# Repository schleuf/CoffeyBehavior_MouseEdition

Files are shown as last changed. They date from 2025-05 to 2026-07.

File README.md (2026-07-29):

<!-- PROJECT LOGO -->
<br />
<div align="center">
  <h3 align="center">A robust and convenient framework for studying the neurobiological substrates underlying individual, strain, and sex differences in fentanyl use disorder in mice</h3>
</div>

<!-- ABOUT THE PROJECT -->
<!-- TOC -->
- [About The Project](#about-the-project)
- [Prerequisites](#prerequisites)
- [Installation](#installation)
- [Generate Raw Manuscript Figures](#generate-raw-manuscript-figures)
- [Custom Implementations](#custom-implementations)
    - [Hardware Setup](#hardware-setup)
    - [MED Software Setup](#med-software-setup)
    - [MATLAB Software Setup](#matlab-software-setup)
- [Detailed Behaivor Protocol](#detailed-behaivor-protocol)
    - [Before Running Behavior](#before-running-behavior)
    - [Running Behavior](#running-behavior)
    - [Planning Cohorts & Ordering Animals](#planning-cohorts--ordering-animals)
    - [Week 0](#week-0)
    - [Week 1](#week-1)
    - [Weeks 2 & 3 Self-Administration](#weeks-2--3-self-administration)
    - [Week 4 & 5 Extinction](#week-4--5-extinction)
    - [Week 6 Reinstatement](#week-6-reinstatement)
    - [Alternative Week 4 Behavioral Economics](#alternative-week-4-behavioral-economics)
<!-- /TOC -->

# About The Project
This GitHub repository contains the code neccessary to generate the figures presented in PUBLICATION INFORMATION

This repository also contains a comprehensive guide for setting up oral fentanyl self-administration and using the accompanying software to analyse the data in a flexible and user friendly manor.

<!-- Prerequisites -->
# Prerequisites
Implementation of the full behavioral pipeline requires Med-PC 4.0 or later (Med-Associates)    

The analysis code has been tested on MATLAB 2024a and later

Required MATLAB Toolboxes:
   ```sh
Curve Fitting Toolbox™   
Statistics and Machine Learning Toolbox™
   ```

Required External Packages:
>https://github.com/piermorel/gramm

# Installation

This Github Repository can be cloned manually, through GitHub Desktop, or through git commands

   ```sh
   git clone https://github.com/schleuf/CoffeyBehavior_MouseEdition
   ```

<!-- USAGE EXAMPLES -->
# Generate Raw Manuscript Figures
Open MATLAB and Navigate to the parent directory for this repository

Run:

   ```sh
   main_MouseSABehavior
   ```

# Custom Implementations
## Hardware Setup
### Single Chamber Parts List  
| Description | Manufacturer | Part # |
|---|---|---|
| Outer Cabinet (1 chamber) | SUNCAST | BMCCPD3000 |
| Outer Cabinet (3 chamber) | SUNCAST | BMCCPD8004 |
| Acoustic Isolation Foam | Auralex | PYRAMIDCHA |
| Camera | Arducam | B0506 |
| Microphone | Pettersson Elektronik | M500-384 |
| Modular Test Chamber Mouse | Med-Associates | ENV-307A |
| Stainless Steel Floor | Med-Associates | ENV-307A-GFW |
| House Light (classic) | Med-Associates | ENV-315M-LED |
| House Light (red) | Med-Associates | ENV-315M-LED |
| Retractable Lever (classic) x2 | Med-Associates | ENV-312-3M |
| Stimulus Light (classic) x2 | Med-Associates | ENV-321M-LED |
| Liquid Delivery Receptacle (tall) | Med-Associates | ENV-303LPHD-4.25 |
| Syringe Pump (3.33RPM) | Med-Associates | PHM-200 |
| Head Entry Detector | Med-Associates | ENV-254-FB |
| SmartCtrl Card | Med-Associates | DIG-716P1 |
| SmartCtrl Panel | Med-Associates | SG-716B |
| Tone Generator | Med-Associates | ENV-323AM |
| Angled Top | 3D Printed | \3D Printed Parts |

### Chamber Wiring
 |     Med-PC #     |     Description    |     Note    |
|---|---|---|
|     Output 1    |     Left Lever Out    |     Active Lever    |
|     Output 2    |     Right Lever Out     |     Optional (Not used in our setup)    |
|     Output 3    |     House Light On    |     Optional   (Not used in our setup)    |
|     Output 4    |     Red House Light On    |     Optional   (Not used in our setup)    |
|     Output 5    |     Left Lever Light    |     Active Lever Stimulus Light    |
|     Output 6    |     Tone On    |     Active   Lever Press Stimulus Tone    |
|     Output 7    |     Right Lever Light    |     Optional   (Not used in our setup)    |
|     Output 8    |     Pump On    |     Liquid Delivery Pump    |
|     Input 1    |     Left Lever In    |     Active Laver    |
|     Input 2    |     Right Lever In    |     Optional (Not used in our setup)    |
|     Input 3    |     Inactive Lever In    |     Non-Retractable Inactive Lever    |
|     Input 4    |     Beam Break In    |     Head Entry Detector for Liquid   Port    |

### Top Down Chamber View


## MED Software Setup
Med-PC Code is available in the folder below and must be compiled prior to use. Inputs and Outputs are defined near the top of the code and may be customezed. Variables for session length, cue timing, pump duration, etc. may be modified in the code or through the Macro.
>./MedPC/MPC/Golden_Liq_SelfAdmin.MPC

   ```sh
   # Editable Inputs, Outputs, and Variable Examples

#  Outputs
    ^LeftLevOut     = 1 
    ^RightLevOut    = 2 
    ^HouseLt        = 3
    ^HouseLtRed     = 4 
    ^LeftLevLt      = 5
    ^RightLevLt     = 7 
    ^Tone           = 6
    ^LiquidDel      = 8
    ^Fan            = 16

#  Inputs
    ^LeftLevIn        = 1 
    ^RightLevIn       = 2 
    ^InactiveIn       = 3
    ^HeadEntry        = 4

# Default setup and trial timing
S.S.1,     
   S1,
     0": ON^Fan;
         SET A(2)  = 180;    \Session length (min)
         SET A(3)  = 4;      \Liquid delivery duration (sec)
         SET A(4)  = 0;      \Lev light delay (sec)
         SET A(5)  = 5;      \Lev light duration (sec)
         SET A(6)  = 0;      \Tone delay (sec)
         SET A(7)  = 5;      \Tone duration (sec)
         SET A(8)  = 0;      \Mag light delay (sec)
         SET A(9)  = 0;      \Mag light duration (sec)
         SET A(10) = 1;      \Active Lev (0:Right 1:Left)
         SET A(11) = 0;      \Liquid delivery delay (sec)
         SET A(12) = 10;     \Total timeout time - time liquid unavailable (sec)
         SET A(16) = 320;    \Maximum Infusions before syringe is empty
         SET A(13) = 180;    \Auto drug delivered (sec) MUST BE SET WITH MACRO IF THIS IS COMMENTED OUT
   ```

Example Med-PC Macros are also available to define subject details, start experiments, and administer shaping rewards through K-Pulses 
>./MedPC/Macro/Golden_Liq_SelfAdmin.MAC

   ```sh
   # Example Macro Text

   TEXTINPUTBOX "Subject in Box 1" "Enter Subject ID:" "S1" #SubB1 
NUMERICINPUTBOX "Weight for Box 1" "Enter weight (grams):" "25" #WeightB1 
NUMERICINPUTBOX "Self-Administration Session" "Enter Training Day:" "1" #SessionB1 
NUMERICINPUTBOX "Auto Shaping Timer" "Enter time between automatic rewards (s)" "60" #ShapeTimeB1
LOAD BOX 1 SUBJ #SubB1 EXPT OralFentSA GROUP One PROGRAM Golden_Liq_SelfAdmin
SET A(13) VALUE #ShapeTimeB1 MAINBOX 1 BOXES 1
SET A(14) VALUE #WeightB1 MAINBOX 1 BOXES 1
SET A(15) VALUE #SessionB1 MAINBOX 1 BOXES 1
   ```
   
## MATLAB Software Setup
The provided MATLAB code can be flexibly modified to run new data generated by your version of Liq_SelfAdmin.MPC
> ./main_MouseSABehavior.m

### Minimal Requirements
- Behavior data  in ./All Behavior
- Experiment Key File: "Experiment Key.xlsx" with following variables (See example)
  - "Run" (number)
  - "Experiment" (categorical: ER, BE, SA)
  - "Date" (Datetime)  - Session (number)
  - "Session Type" (categorical: PreTraining, Training, Extinction, Reinstatement, BehavioralEconomics)
  - "Fentanyl Concentration (ug/ml)" (number)
  - "Volume per dose (mL)" (number)

- Subject Key File: "Subject Key.xlsx" with the following variables (See example, adding extra variables is ok)
  - "Tag Number" (Categorical)
  - "Run" (Number)
  - "Strain" (Categorical)
  - "SelfAdministration" (Logical)
  - "Extinction" (Logical)
  - "Reinstatement" (Logical)
  - "BehavioralEconimics" (Logical)
  - "InlcludeBehavior" (Logical)
  - "RemoveSession" {Cell of Numbers}

### All User Editable Variables are available and described in the first block of code.
   ```sh
# USER EDITABLE SETTINGS
runNum = 'all'; # options: 'all' or desired runs separated by underscores. Must match numbers in Experiment Key (e.g. '1', '1_3_4', '3_2')
runType = 'all'; # options: 'ER' (SA & Extinction & Reinstatement), 'BE' (Behavioral Economics), 'SA' (Self Administration), 'all' (All run seperately)
createNewMasterTable = true; # true: generates & saves a new master table from medPC files in datapath. false: reads mT in from masterTable_flnm if set to false, otherwise 
firstHour = true; # true: acquire data from the first-hour of data and analyze in addition to the full sessions (Important for camparing behavior to 1h reinstatement session).
excludeData = true; # true: excludes data based on the 'RemoveSession' column of Subject Key
acquisition_thresh = 10; # to be labeled as "Acquire", animal must achieve an average number of infusions in Training sessions greater than this threshold
acquisition_testPeriod = {'Training', 'last', 10}; # determines sessions to average infusions across before applying acquisition_thresh. second value can be 'all', 'first', or 'last'. if 'first' or 'last', there should be a 3rd value giving the number of days to average across, or it will default to 1. 
maxLatency = 360; # maximum time in seconds between an active lever press and head entry to be factored into latency calculations
pAcq = true; # true: plot aquisition histogram to choose threshold 
interpWeights = false; # true: interpolate daily weights from weekly weights
interpWeight_sessions = [1,6,11,16,21]; # [sessions with true weights for interpolation]
addROI = true; #true: append master table with ROI data - Requires ROI data sheets with "TagNumber" column and "Video" Column
run_BE_analysis = true; # Run Behavioral Economics analysis?
run_withinSession_analysis = true; # Run within-sessions analysis?
run_individualSusceptibility_analysis = true; # Run individual risk analysis?

# FIGURE OPTIONS
# Currently, if figures are generated they are also saved. 
saveTabs = true; # true: save matlab tables of analyzed datasets
dailyFigs = true; # true: generate daily figures from dailySAFigures.m
pubFigs = true; # true: generate publication figures from pubSAFigures.m
indivIntake_figs = false; # true: generate figures for individual animal behavior across & within sessions (useful for troubleshooting but produces a lot of figures)
groupIntake_figs = true; # true: generate figures grouped by sex, strain, etc. for animal behavior across & within sessions
severity_figs = true; # true: generate severity figures
figsave_type = {'.png','.fig'}; # file types for figure outputs. May be any MATLAB standard image or figure type

# color settings chosen for publication figures. See GRAMM documentation for HLC Color formatting
gramm_C57_Sex_colors = {'hue_range',[40 310],'lightness_range',[95 65],'chroma_range',[50 90]};
gramm_CD1_Sex_colors = {'hue_range',[85 -200],'lightness_range',[85 75],'chroma_range',[75 90]};
gramm_Strain_Acq_colors = {'hue_range',[25 385],'lightness_range',[95 60],'chroma_range',[50 70]};
col_M_c57 = [0, 0.7333, 0.5647]; # Hard code color for c57 Males
col_F_c57 = [1, 0.4196, 0.2902]; # Hard code color for c57 Females
col_M_CD1 = [0.6392, 0.5373, 1]; # Hard code color for CD1 Males
col_F_CD1 = [0.7765, 0.5922, 0]; # Hard code color for CD1 Females
   ```

# Detailed Behaivor Protocol
## Before Running Behavior
### Animal Handling
Consistent handling is important to running delicate behaviors. Animals should be handled for at least 5m each daily in the week prior to starting SA. Researchers should complete Animal Handling Basics courses before physically handling animals.

### Changing Bedding (Mondays)

Every Monday, before running behavior, new bedding must be added to each of the chambers.

### Weighing Animals (Mondays)

Every Monday, animals must be weighed BEFORE running behavior. Weigh and write down the weight for each animal before putting them into their chamber.

### Update the Macro (Daily)

On Monday update the MedPC macro file with each animal’s weekly weight. Every other day, update the macro with the running session. If this is incorrect it may be fixed while running the macro (in question dialog) and it will additionally be checked by the final analysis code against the experiment key.

### Cleaning Chambers (Fridays)

After closing behavior on Friday, dump bedding into the trash, and clean chambers. Wash off any excess bedding from the removable bedding holders in the sink and use clidox to clean the bedding holders and the floors/walls of the MedPC chambers. Clean well!

## Running Behavior

### Loading MedPC Macros & Initializing MedPC Sessions

These instructions assume you are using OBS to record from multiple USB cameras. Generally, up to 6 cameras can be recorded at the same time on one computer. OBS can record all 6 videos to 1 file to be split later, or it can record each individually with “Source Record”. Instruction for setting up OBS with “SourceRecord” can be found here: <https://obsproject.com/forum/resources/source-record.1285/>

### Starting A Session

Hint: Use a macro pad to signal both pieces of software, and a USB splitter if on 2 computers.

1. Load MedPC Macros and Initialize session.
    1. Example Macro files are included in the Github Repository.
2. Open OBS and check cameras are functioning and ‘source record’ is ready
3. Use a Macro pad to signal both pieces of software to start (example “Alt+f11” is run for both)
4. Check that the session is running and your cameras are recording

### Closing A Session

1. Check that the session is closed on MedPC
2. Use a Macro pad to turn off video on OBS (Alternatively set max recording length)

## Planning Cohorts & Ordering Animals

Note: The first day of your experiments (magazine training) will always be on a Friday.

Acceptable age range of experimental mice, day one of experiment: 7-8 weeks old. Some experiments use mice between 7-10 weeks old, but so far, all animals we have used started experiments at 7 weeks old.

## Week 0

### Ear Tagging & Behavior Master Key

On Friday, a week before your magazine training, animals should be given unique identifiers (ear tags or snips) and added to the ‘Master Key’ excel spreadsheet. Example in the GitHub Repo

### Handling

The week leading up to magazine training, each animal should be handled daily for 5min to get them used to researcher intervention and a novel hand picking them up/entering their home cage.

Why do we do this? Mice, in nature, are prey to many species that pick them up or move fast towards them from above. In handling these mice, a week before regularly picking them up, we mitigate any unnecessary stress that could be introduced by a fast-moving object picking them up from above. Be aware that unhandled mice may be fearful of your hand entering their cage and picking them up in a similar way that their hunters do in nature. NOTE: This is a general best practice for mouse related research, and it’s important to know that the stress related affects that could occur from unhandled mice may result in lower acquisition. Also note that these mice will be put into MedPC chambers later in the week, which will be a completely novel environment to them – reducing the number of novelties can help reduce the time to acquisition, and general acquisition rates in each cohort.

### Saccharin Pre-Exposure (Magazine Training)

Saccharin is a non-nutritive, zero calorie sweetener that’s much sweeter than sugar. The sweetness of this reward helps the mice learn the cue-reward response and being non-nutritive/non-caloric is important to maintain the health of these animals and ensures that any future fentanyl related behaviors cannot be attributed to differences in saccharin intake.

Magazine Training is a one-hour session where the animals are run under normal training conditions (i.e. can lever press for reward and receive reward), while simultaneously receiving an automatic reward each minute (separate from any active lever mediated rewards). Since these chambers are novel environments, the constant automatic rewards help expedite their ability to learn that there are cues (tone and lever light) associated with the delivery of a liquid in the hopper. The sweetness of the saccharin is used to drive the animals desire to consume and seek the dispensed liquid (NOTE: these animals are not water deprived).

### Making Saccharin Solution

During saccharin pre-exposure, we use a mixture of 0.1% saccharin in Hydro pack H<sub>2</sub>O. For 8 chambers we use 250ml of H<sub>2</sub>O and 0.25g saccharin.

## Week 1

### Saccharin Fade

Purpose: Use saccharin to enforce reward seeking while simultaneously weaning animals off saccharin. This shows that any persistent reward seeking is due to fentanyl seeking as opposed to saccharin seeking. 3hr sessions each day.

Saccharin Solution: Use hydropack solution with saccharin (0.1, 0.08, 0.06, 0.04, 0.02, 0.00%) and fentanyl (70ug/ml). NOTE: Each day your solution must be diluted using a hydropack solution with 0% saccharin and fentanyl (70ug/ml).

### Shaping

Automatic reward timer: Automatic rewards are administered to each medpc chamber every 10, 20, 30, 40, 50 mins, depending on the training session (1/2/3/4/5). The automatic reward timer can be set in the medpc macro text file, or via the medpc input boxes displayed on macro playback.

Manual Shaping schedule: Each day has unique start times and procedures for shaping. Refer to the list of days below for specifics. The keys to shaping are to reward successive approximations of a lever press, and to be a sparing as possible. You don’t want animals to become reliant on manual rewards. Shaping must be done consistently and within a very tight time window around behavior. The best way to do this is to have a shaping macro key pad that signals a K-Pulse to Med PC. Shape the macro pad identically to the video window to facilitate watching multiple animals with precision and speed.

### Monday

Start: 10min after session start

Do: administer rewards on **active lever approach** and **region adjacency**. NOTE: make sure the animals head is oriented towards the active lever and not the hopper.

Active lever approach = anytime the animal is moving towards and looking at the active lever.

Region adjacency = if the animal is grooming adjacent to the active lever (or hopper), administer a reward anytime they look at the active lever. Also administer rewards anytime a body part of theirs (particularly forepaw or hindpaw) contacts the lever. Provide no more than 15 manual rewards.

### Tuesday

Start: 20min after session start

Focus: Continue to administer rewards on active lever approach and region adjacency. Aim for rewarding further successive approximations of a lever press. Only shape animals with less than 5 active lever presses. Provide no more than 15 manual rewards.

### Wednesday

Start: 30min after session start

Continue to administer rewards on active lever approach and region adjacency for slow learning animals. Reward lever contacts that don’t complete a press. Focus on snout or paw contact. Aim for rewarding further successive approximations of a lever press. Try not to go backwards to adjacency. Only shape animals with less than 7 active lever presses. Provide no more than 15 manual rewards.

### Thursday

Start: 40min after session start

Reward lever contacts that don’t complete a press. Focus on snout or paw contact. Aim for rewarding further successive approximations of a lever press. Try not to go backwards to adjacency. Only shape animals with less than 10 active lever presses. Provide no more than 15 manual rewards.

### Friday

Start: 1hrs after session start

Reward lever contacts that don’t complete a press. Focus on snout or paw contact. Aim for rewarding further successive approximations of a lever press. Try not to go backwards to adjacency. Only shape animals with less than 10 active lever presses. Provide no more than 15 manual rewards.

## Weeks 2 & 3 (Self-Administration)

Self-administration: 70ug/ml fent in hydropack water. Rewards administered exclusively by the animal. Generally, no manual training or automatic reward. Set automatic reward time to 1000000 in macro (any number longer than the session in seconds). Animals run for 3hrs.

## Week 4 & 5 (Extinction)

Two weeks of 3hr long behavior sessions. Active lever is accessible, but no tone, lever light, or reward are administered after an active lever press. Use \_EXT MED-PC code.

## Week 6 (Reinstatement)

Animals run for a single day, where the tone and lever light return and follow every active lever press. Liquid rewards are not administered (remove the syringe). Sessions only run for 60 minutes to allow for perfusions within the immediate early gene expression window.

## Alternative Week 4 (Behavioral Economics)

Self-administration with a decreasing concentration of fentanyl per reward each day (222, 125, 70, 40, 22ug/ml). Quantifies consumption/price relationship for each animal’s reward seeking behavior (read [this paper](https://www.nature.com/articles/npp2008195) for review). We expect self-administering (/reward seeking) animals to change their consumption relative to the concentration of fentanyl administered. In particular, we expect an increased amount of lever pressing at lower concentrations of fentanyl and decreased (or the same) levels of lever pressing at higher concentrations of fentanyl (depending on the animal’s tolerance). It is essential to measure the fentanyl intake manually in case fentanyl is not consumed. Measure the syringe volume before the session, and after the session retract the remaining fentanyl from the dish and measure the final volume.

[][cc-by-nc-nd]   

This work is licensed under a
[Creative Commons Attribution-NonCommercial-NoDerivs 4.0 International License][cc-by-nc-nd].

[cc-by-nc-nd]: http://creativecommons.org/licenses/by-nc-nd/4.0/
[cc-by-nc-nd-shield]: https://img.shields.io/badge/License-CC%20BY--NC--ND%204.0-lightgrey.svg

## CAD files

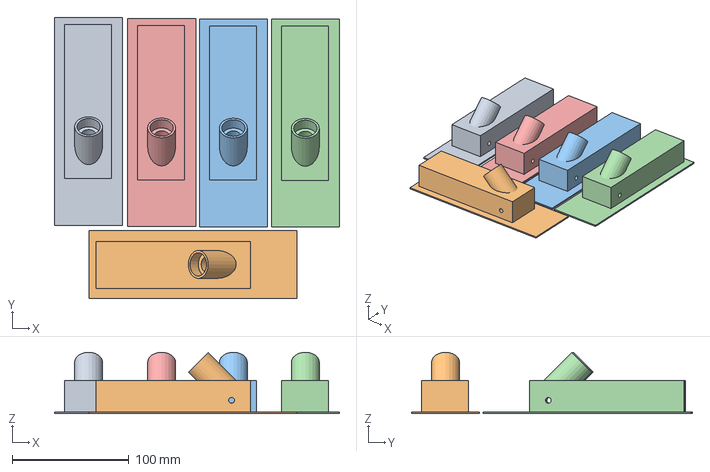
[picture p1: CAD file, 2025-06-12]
3D Printed Parts/Pellet_Recepticle_TubeInsideHole_Liquid23mm-HoleBlocker_Rev2-withTreeSupport-5.3mf
243.9 x 240.5 x 52.5 mm
Pellet_Recepticle_TubeInsideHole_Liquid23mm-HoleBlocker_Rev2.stl x 5

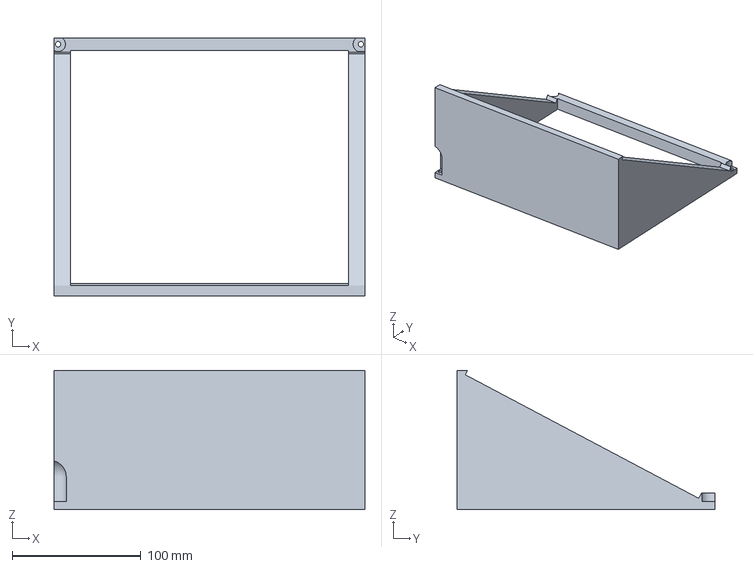
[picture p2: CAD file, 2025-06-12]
3D Printed Parts/AngledCageTopAcrylic-Small.3mf
241.3 x 200.0 x 108.0 mm

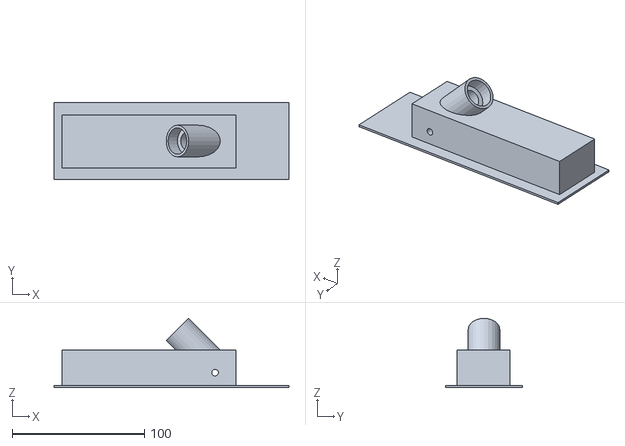
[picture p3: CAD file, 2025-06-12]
3D Printed Parts/Pellet_Recepticle_TubeInsideHole_Liquid23mm-HoleBlocker_Rev2.stl
178.0 x 58.4 x 52.5

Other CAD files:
3D Printed Parts/AngledCageTopAcrylic-Small.stl

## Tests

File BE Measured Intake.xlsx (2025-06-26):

TagNumber | Strain | Sex | Weight (g) | Day | Dose (μg/ml) | mL Start | mL End | Loss Adjustment | mL Taken | Drug Volume (μg) | measuredIntake
651 | c57 | Male | 26.6 | 1 | 222 | 2 | 1.7 | 0 | 0.3 | 66.6 | 2503.759398
651 | c57 | Male | 26.6 | 2 | 125 | 2.5 | 1.9 | 0 | 0.6 | 75 | 2819.548872
651 | c57 | Male | 26.6 | 3 | 70 | 3 | 2.3 | 0 | 0.7 | 49 | 1842.105263
651 | c57 | Male | 26.6 | 4 | 40 | 3 | 2.4 | 0 | 0.6 | 24 | 902.2556391
651 | c57 | Male | 26.6 | 5 | 22 | 3 | 2.3 | 0 | 0.7 | 15.4 | 578.9473684
652 | c57 | Male | 22.6 | 1 | 222 | 2 | 1.8 | 0 | 0.2 | 44.4 | 1964.60177
652 | c57 | Male | 22.6 | 2 | 125 | 2.5 | 2.2 | 0 | 0.3 | 37.5 | 1659.292035
652 | c57 | Male | 22.6 | 3 | 70 | 3 | 2.3 | 0 | 0.7 | 49 | 2168.141593
652 | c57 | Male | 22.6 | 4 | 40 | 3 | 1.9 | 0 | 1.1 | 44 | 1946.902655
652 | c57 | Male | 22.6 | 5 | 22 | 3 | 2 | 0 | 1 | 22 | 973.4513274
653 | c57 | Male | 23 | 1 | 222 | 1.7 | 1.5 | 0 | 0.2 | 44.4 | 1930.434783
653 | c57 | Male | 23 | 2 | 125 | 1.9 | 1.5 | 0 | 0.4 | 50 | 2173.913043
653 | c57 | Male | 23 | 3 | 70 | 2.8 | 2.1 | 0 | 0.7 | 49 | 2130.434783
653 | c57 | Male | 23 | 4 | 40 | 2.4 | 1.7 | 0 | 0.7 | 28 | 1217.391304
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

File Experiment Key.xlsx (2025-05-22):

Run | Experiment | Date | Session | Session Type | Fentanyl Concentration (ug/ml) | Volume per dose (mL)
1 | ER | 2024-04-29 | 1 | PreTraining | 70 | 0.01931
1 | ER | 2024-04-30 | 2 | PreTraining | 70 | 0.01931
1 | ER | 2024-05-01 | 3 | PreTraining | 70 | 0.01931
1 | ER | 2024-05-02 | 4 | PreTraining | 70 | 0.01931
1 | ER | 2024-05-03 | 5 | PreTraining | 70 | 0.01931
1 | ER | 2024-05-06 | 6 | Training | 70 | 0.01931
1 | ER | 2024-05-07 | 7 | Training | 70 | 0.01931
1 | ER | 2024-05-08 | 8 | Training | 70 | 0.01931
1 | ER | 2024-05-09 | 9 | Training | 70 | 0.01931
1 | ER | 2024-05-10 | 10 | Training | 70 | 0.01931
1 | ER | 2024-05-13 | 11 | Training | 70 | 0.01931
1 | ER | 2024-05-14 | 12 | Training | 70 | 0.01931
1 | ER | 2024-05-15 | 13 | Training | 70 | 0.01931
1 | ER | 2024-05-16 | 14 | Training | 70 | 0.01931
1 | ER | 2024-05-17 | 15 | Training | 70 | 0.01931
1 | ER | 2024-05-20 | 16 | Extinction | 0 | 0
1 | ER | 2024-05-21 | 17 | Extinction | 0 | 0
1 | ER | 2024-05-22 | 18 | Extinction | 0 | 0
1 | ER | 2024-05-23 | 19 | Extinction | 0 | 0
1 | ER | 2024-05-24 | 20 | Extinction | 0 | 0
1 | ER | 2024-05-28 | 21 | Extinction | 0 | 0
1 | ER | 2024-05-29 | 22 | Extinction | 0 | 0
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

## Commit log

2025-06-12 Updating Repository for Community Resource
    Adding new readme and protocols
    [2025.06.12.Fentanyl.Estimation.Example.xlsx, AngledCageTopAcrylic-Small.3mf, AngledCageTopAcrylic-Small.stl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]
2025-06-26 Big Clean Up
    preping for publication
    changed file names
    collapsed the stats files
    tested and should work :)
    [2024.12.09.BE Intake Canonical.xlsx, BE Measured Intake.xlsx, Subject Key.xlsx]
2025-07-01 Added ROI Data
    This update allows the ROI data to be imported and joined to the behavior data table.
    [07_01_ROI_C57.xlsx, 07_02_ROI_C57.xlsx, 07_03_ROI_C57.xlsx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]
2025-07-22 Major Readme Update & Subject Key Fix
    Major Readme Update & Subject Key Fix
    [Subject Key.xlsx]

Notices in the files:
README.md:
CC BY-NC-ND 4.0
